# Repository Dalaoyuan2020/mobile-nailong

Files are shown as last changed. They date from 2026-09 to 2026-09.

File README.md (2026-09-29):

# 移动奶龙 / Mobile Nailong

产品目标是**爆改普通行李箱，实现平稳移动、手机遥控与自动跟随主人**；奶龙是可拆装的趣味外观。先完成低速遥控和跟随，再验证裸箱装物、手推与日常随行能力。当前交付处于方案/粗模阶段，尚无可运行实车。

**交给另一Agent审查：先读 [PRD 产品需求](docs/PRD.md) → [PDR 初步设计评审](docs/PDR.md) → [审查任务与证据入口](docs/REVIEW_HANDOFF.md)。** 本方案在 `codex/case26-shell-first` 分支与[草稿PR #1](https://github.com/Dalaoyuan2020/mobile-nailong/pull/1)，未合入前不要用旧main代表当前方案。

当前方案：**正常竖立的行李箱藏在奶龙立牌背后，双管拉杆贴板背，轮子在箱底。** 按参考照片近似描出圆头、鼓肚、抱腹双手和两只脚；立牌是一张 8 mm 平板，彩色图案为印刷示意。

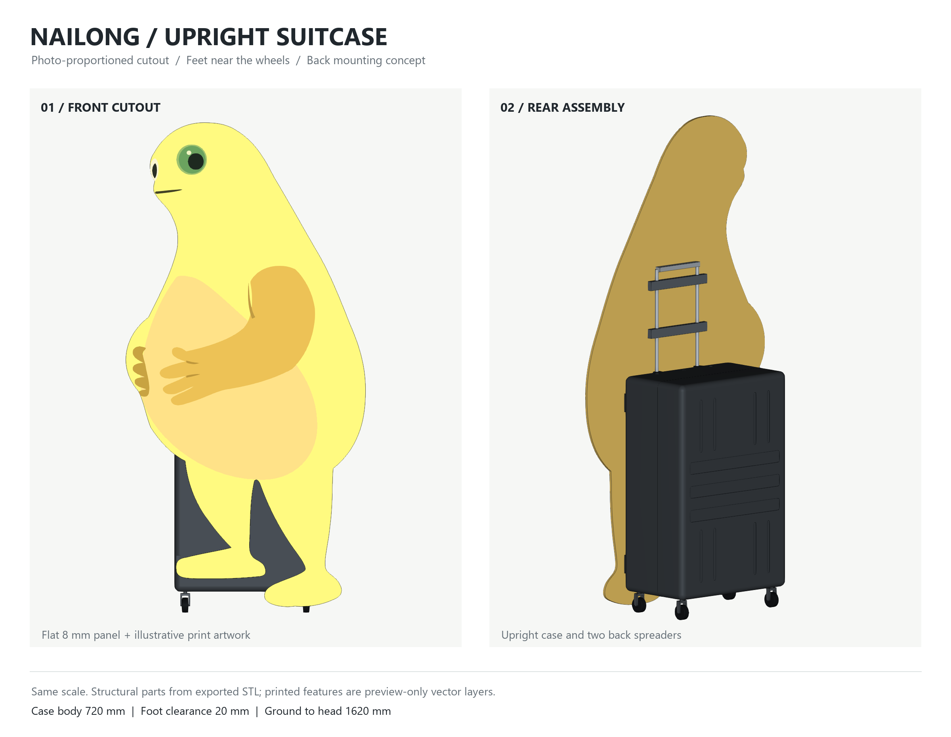
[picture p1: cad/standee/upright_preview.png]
奶龙立牌与背后竖箱


## 当前交付

- [可整块复制的 prompt](docs/PROMPT_STAND_HANDLE.md)
- [装配 STEP](cad/standee/standee_assembly.step) / [STL](cad/standee/standee_assembly.stl) / [侧视](cad/standee/upright_side.png)
- [奶龙轮廓源码](cad/standee/nailong_profile.py) / [正面图案 SVG](cad/standee/front_artwork.svg) / [总装源码](cad/standee/standee.py)
- [材料与候选器件清单](docs/BOM.md) / [功能实现路线](docs/FUNCTIONS.md) / [可复现仿真](simulation/README.md)
- [交互仿真独立页](simulation/nailong-motion.html)：下载/克隆后用浏览器打开；GitHub文件页只展示源码。

默认板高 **1600 mm**，按照片比例宽约 **792 mm**，最低脚尖离地 **20 mm**，头顶离地 **1620 mm**；可用 `--height 1800` 改为 1800 mm 板、约 891 mm 宽、总高 1820 mm。轮廓和图案是参考照片的手工近似，尚非最终印刷稿。

箱壳沿用原 720×470×290 mm 两半壳，只旋转成高720、宽470、深290 mm的竖箱，箱底Z70、箱顶Z790。原 [case26 文件](cad/case26/) 保持原设计坐标，仅总装副本切嵌入式拉杆导座槽。拉杆双管Ø12、管距180，伸出箱顶350 mm。板背X145贴箱面与双管；背面两条概念压条中心Z920/1080，夹具、紧固件和承载能力留待实物验证，正面不画绑带。

当前 CAD 四个轮子是被动外形占位：Ø50、中心X±105/Y±200，左右距400、前后距210 mm。仿真的双电机差速驱动和候选80 mm轮尚未装进CAD；换轮须复核离地间隙、轮舱和接地点。旧540 mm轴距属于横放方案，不用于当前竖箱。

## 复现

```powershell
python -m pip install -r cad/standee/requirements.txt
python cad/handle/handle.py
python cad/standee/nailong_profile.py
python cad/standee/standee.py
python cad/standee/render_preview.py
```

导出过程检查有效实体、STEP回读、STL水密、零件干涉和贴合；印刷面不计入实体STEP。物理仿真使用假设质量与接地点，不能替代称重、实际制动和载荷试验。

## 历史方案

[箱壳初版 prompt](docs/PROMPT_CASE_FIRST.md)、[旧尺寸](docs/DIMENSIONS.md)、[旧计划](docs/PLAN.md)、[旧分层](docs/LAYERS.md)、[旧重心](docs/PHYSICS.md)、[旧电控](docs/ELECTRONICS.md)保留阶段记录。当前需求以[PRD](docs/PRD.md)、执行进度以[任务表](docs/TASKS.md)、外形以[竖箱奶龙 prompt](docs/PROMPT_STAND_HANDLE.md)为准；[资料摘录](docs/SOURCES.md)不作为本机性能证明。

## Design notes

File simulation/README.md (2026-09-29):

# 竖箱移动方案：第一轮筛查

浏览交互结果：下载/克隆后打开 [nailong-motion.html](nailong-motion.html)；GitHub文件页不执行HTML。它是修复后内联可视化的独立导出版，可调高度、配重、速度、转弯与风。[fragment源文件](nailong-motion.fragment.html)保留编辑入口；页面不连接硬件，不实现自动跟随。导出页使用随附样式和状态桥接，通用UI资源可能从允许的CDN加载。

已检查阻断网络时核心图形与控件仍可使用。数值的可复现来源为下面的Python模型；修改fragment后须重新导出完整页，不能只更新其中一份。当前完整页由visualize技能的`python scripts/render.py <fragment> <完整页>`导出，阅读和运行完整页不要求安装该技能。

需求与当前差距见[PRD](../docs/PRD.md)、[PDR](../docs/PDR.md)。本轮只计算当前竖箱奶龙构型；PRD的裸箱0.8 m/s、载物与跟随指标尚未在这里完成独立构型验证，不能只拖动速度滑杆就视为验收。

从仓库根目录运行：`python simulation/simulate.py`。脚本仅用 Python 标准库，参数在 `parameters.json`，会重写 `results.json` 并运行边界校验。一次比较可用 `python simulation/simulate.py --height 1.8 --bottom 0.02 --output simulation/results-1800.json`；默认输出也包含 1.6 / 1.7 / 1.8 m 的对比。

当前 CAD 是被动 Ø50 箱轮；此处计算的是**待实现的后两驱动轮 + 前两万向轮**。接地点 X=±105、Y=±200 mm，后驱动轴 X=-105 mm；轨迹的参考点是该轴中点。支持接地点随脚轮旋转变化尚未建模。Ø80 是备选轮径，采用时必须同时改 CAD 轮舱和离地高度。

默认 0.3 m/s、加减速度 0.25 m/s²、转弯半径不小于 1.5 m，前进左/右转，不原地转、不自动倒车。输出包含直行停车、最小半径转弯停车、断连停车三种轨迹。通信失联 0.2 s 后由仍正常供电的控制器减速停车；默认计算距离 0.24 m，不含检测误差、打滑和控制器失效，断电停车另测。

质量、重心、滚阻、减速度、风阻系数均为**假设**。板轮廓几何可来自照片，但均匀板重与均匀风压仍是假设。6 kg 配重是比较起点，不是实测需求；配重需低位固定，不能自由滑动。固定件 0.5 kg 是暂估。轮距 400 mm/前后距 210 mm 只对应当前竖箱，不沿用历史横箱的 540 mm。

修改 `standee_height_m` 会按相同比例缩放照片轮廓的高和宽、Y/Z 形心与面积；`standee_bottom_m` 单独平移板底和形心高度。默认按 1.6 m 板 1.5 kg 的固定面密度计算，1.8 m 板推算为 1.898 kg；可用 `standee_mass_override_kg` 替换为实测质量。风压作用点采用当前面积形心。`standee_reference` 保留与 CAD 同源的 1.6 m 轮廓基准，输出 `standee_resolved` 给出本次实际值，包含板底/顶部高度。

重心由质量加权计算；接触合力在前后/左右支持边界内只表示通过本准静态筛查。刹车或加速、迎面风、逆向坡度采用最不利同向力矩；转弯用 v²/R。风覆盖整张板，不减掉箱体遮挡。迎风面积/作用点变化、阵风、夹具/KT 弯曲、台阶冲击、脚轮拖曳和动态翻倒都未验证。风阈值是翻倒边界，绝非运行许可风速。

扭矩列出轮端接触需求和减速器输出选型值，后者计入效率 0.7 与系数 2；对两驱动轮平均分力。电机应按实际工作转速下的**持续扭矩**、热限制和驱动电流选，不能用堵转扭矩。另需做后轮附着/制动驻坡试验。

依据：[WPILib 差速运动学](https://docs.wpilib.org/en/stable/docs/software/kinematics-and-odometry/differential-drive-kinematics.html)、[NASA 风阻公式](https://www1.grc.nasa.gov/beginners-guide-to-aeronautics/drag-equation/)。阻力系数 1.2 是本项目假设，未对奶龙切型板标定。

下一步：量整机/各部件重量及轮廓、称重或悬挂测重心；低速架空验证左右轮和失联停止；再在有人监护的空地测试直行、缓转、停车。结构/多体动态仿真与实车测试应在驱动、夹具和质量确认后进行。

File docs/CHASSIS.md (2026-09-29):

# L1 底盘：买还是自制

> 历史横放底盘选型：当前为竖立箱体与普通箱轮，本轮没有驱动底盘；下文采购与承载结论需按新方案复核，几何见 [当前 prompt](PROMPT_STAND_HANDLE.md)。

偏好：**能自制就自制**。工期紧再买现成。

判据只看一个数：距展示 / 路演还剩几天。

| 剩余 | 走哪条 |
|---|---|
| ≥ 10 天 | 自制 |
| 5–9 天 | 自制架 + 买电机遥控，不自绘 PCB |
| < 5 天 | 买 20 kg 成品底盘，箱子直接扎上去 |

---

## 价档分档（2026-09-29 淘宝见到的价）

| 档 | 大概 | 什么 | 能不能驭 17–22 kg |
|---|---|---|---|
| 电赛板 | 20–80 | 亚克力 / 薄铝 + TT 电机 | 不行 |
| **自拼重载** | **150–250** | 铝板 + 520/775 减速电机 + 驱动 + 2.4G 遥控 | 能，要自己对轮距限速 |
| 成品 20 kg 平台 | 300–450 | 500×300 铝合金四驱，常见一张 **395** | 能，开箱驭箱 |
| 履带 / 车间平车 | 800–几千 | 果园车、工厂平车 | 过大，不买 |

搜索词：

- 自制：`520 减速电机` `775 减速电机` `BTS7960` `2.4G 遥控车` `94dd板 400x600x5`
- 现成：`94dd合金重载底盘 20kg 四驱 遥控`

---

## 路径 A · 自制（偏好）

零件约 150–250：

| 件 | 约 |
|---|---|
| 铝板 400×600×5 或 500×300×5 | 30–60 |
| 520 或 775 减速电机 × 2（后驱） | 50–80 |
| 高流驱动 BTS7960 或双路大电流 | 20–40 |
| 万向轮 4 寸 × 2（前） | 15–25 |
| 驱动轮 + 联轴 | 20–40 |
| 2.4G 遥控接收 | 25–40 |
| 12V 5Ah 三元或铁硼 | 30–50 |
| 螺丝拐角 | 10 |

形状：后两轮差速驱动，前两轮万向从动。不要麦轮。
轮距 ≥ 360 mm，轴距 ≥ 480 mm。
PWM 必须 2 秒斜率，禁止两轮反转原地转。

工时大概 3–5 晚：下单 1 天 + 对孔装配 1 晚 + 调速 1 晚 + 扎箱跑 1 晚。

## 路径 B · 现成（时间不够）

一张标 20 kg 的铝合金四驱平台，常见 **395**，台面约 500×300。
箱子闭死扎在台面上。遥控太敏就把摇杆行程限一半。

## V1 共同部分（两条路都要）

- 26 寸硬壳 80–150
- 1.6 m KT 立牌 40–80
- 配重 8 kg
- 扎带 20
- 拆原装万向轮
- V1 **不开箱**

V1 合计：自制约 **350–550**；现成约 **420–750**。

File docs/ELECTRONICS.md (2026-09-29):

# 电控

> 历史草案：下文的 BLE RSSI 跟随和倾斜后退不用于当前方案。当前实现路线见 [FUNCTIONS.md](FUNCTIONS.md)，选型见 [BOM.md](BOM.md)；倾斜或失联应停机，不自动后退。

建模不依赖这一页。装配时用。

- ESP32
- 双路驱动 + 两只减速电机（后轮）
- MPU6050 贴在立牌背面中高，不是贴在箱上
- 超声 × 3：箱前缘中、左前、右前
- DFPlayer + 喇叭
- 电机电源串急停
- 手机 BLE 摇杆；跟随 = 跟主人手机 RSSI

PWM 斜率：摇杆打满也要 2 秒才到 0.30 m/s。禁止原地甩尾。
俠仰/横滚 > 8° 持续 200 ms → 停转并后退。

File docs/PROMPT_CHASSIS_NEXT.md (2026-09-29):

# PROMPT · 箱子已有，这一轮只做底盘

> 历史横放底盘 prompt，已停用。当前竖立箱体仅有普通箱轮，没有驱动底盘；姿态和轮位见 [当前 prompt](PROMPT_STAND_HANDLE.md)。

从下面 `---` 复制到文末，贴给本地 Claude / Codex。

---

注意：以下横放底盘方案仅留档，不能直接套到当前竖立箱体；本轮不按此旧 prompt 新建驱动底盘。

你在仓库 `mobile-nailong` 里推进 L1。

箱子已经在本地画好了。**不要重画箱子，不要改箱子外形。**
这一轮只设计铝底盘板 + 四轮装配。
不要建立牌、不要建绑带、不要建 ESP32 盒、不要建配重块。

路径：自制底盘（路径 A）。参考 `docs/CHASSIS.md` 和 `docs/LAYERS.md`。

## 约束

- 箱子躺平。底盘在箱底下面。
- 坐标跟箱子一致：原点在箱底外表面中心，+X 前进，+Z 向上。
- 箱底四个 M6 轮装孔已经按轮距 400 mm、轴距 540 mm 布好。底盘的四个孔必须对上这四个孔。
- 底盘板厚 5 mm，材料 6061。
- 底盘平面尺寸约 500 × 360 mm，不得比箱脚印（720 × 470）更宽超过 20 mm。
- 后两轮驱动（差速），前两轮万向从动。轮径 50 mm。
- 不要麦克纳姆轮。不要履带。
- 电机用简模：直径 37 mm 的圆柱，长 70 mm，贴在底盘下表面靠后轴。
- 电机和轮不得碰箱壳。离地间隙 ≥ 15 mm。
- V1 箱子不开盖。底盘不要挡箱盖分型线，但不用为开盖让位。

## 要交付

放到 `cad/chassis/`：

1. `chassis.scad` 或 `chassis.py`（CadQuery / OpenSCAD，和箱子同一套工具）
2. 和已有箱子装在一起的装配（箱在上，底盘在下）
3. `NOTES.md`：十行以内，写板尺寸、四孔坐标、轮距轴距、离地间隙

先画底盘板和四孔，再画轮和电机。不要改箱。画完等我看装配侧视。

---

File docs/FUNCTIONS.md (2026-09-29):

# 功能实现路线 · 先形状，再能稳稳地走

完整产品范围见[PRD](PRD.md)，可行性缺口见[PDR](PDR.md)。**手机遥控与自动跟随均为核心需求**：M1先验证稳定遥控，M2必须交付低速跟随，M3再验证裸箱日常使用；完成M1不能宣称整个产品完成。

当前交付是正常竖箱、贴箱奶龙切型板与背部固定占位的粗模；没有驱动底盘或已运行固件。板高默认 1600 mm，可调至 1800 mm，脚底 Z=20 mm，因此龙头离地约 1.62–1.82 m。它不从箱顶再叠高。固定方法未锁定，先验证背撑、两点分压夹持和下部承托。

## M1 · 稳定遥控工程样机

| 功能 | 实现方法 | 首版验收目标 |
|---|---|---|
| 手机遥控前进/停止 | 手机 BLE 控制界面 → ESP32 → 两路 H 桥 → 后两带编码器减速电机 | 放开摇杆停；最高 0.30 m/s；加速度不超过 0.25 m/s²；首版不开放倒车 |
| 缓慢转弯 | 后两固定驱动轮差速，前两万向；编码器闭环修正左右轮速 | 转弯半径不小于 1.5 m；禁原地自旋和左右轮反向甩尾 |
| 通信丢失停机 | 指令含序号/心跳；超时后目标速度归零，由健康且正常供电的控制器受控减速 | 台架初值 200 ms，实测通信延迟与停车距离后调整；恢复通信不自行起步 |
| 近障停车 | 三个前向传感器 + 低位触碰条进入统一停车状态 | 障碍消失后仍需人工重新使能；不自动后退 |
| 倾斜停车 | 箱体 IMU，融合倾角和角速度；阈值由重心/倾覆仿真与实物测试定 | 避开加速噪声误判；倾斜时停机锁定，不用“后退”补救 |
| 实体急停 | 常闭急停回路切断驱动电源；控制器独立低压供电记录状态 | 急停复位不自动启动；断电后的滑行距离单独实测 |

限速、阈值和停车逻辑是待实现的设计目标。0.30 m/s、减速度 0.25 m/s²、200 ms 延迟的理想停车距离为 `v×延迟 + v²/(2a) ≈ 0.24 m`，尚未包含传感器滤波、打滑、脚轮摆动和障碍余量；检测触发距离须大于实测停车距离再留余量。此数值依赖健康控制器受控减速，不能把断电等同于立即刹停，坡道保持需另外验证或增加机械驻车制动。[仿真假设与复现](../simulation/README.md) · [本轮计算结果](../simulation/results.json)

```mermaid
flowchart LR
  Phone[手机 BLE 摇杆与心跳] --> Controller[ESP32 状态机与速度闭环]
  Sensors[编码器 / 箱体 IMU / 距离与触碰] --> Controller
  Controller --> Driver[左右 H 桥]
  Driver --> Wheels[左右后驱动轮]
  Battery[成品电池与保险丝] --> Stop[实体急停开断回路]
  Stop --> Driver
  Battery --> Logic[逻辑电源]
  Logic --> Controller
```

控制状态按“待机 → 人工使能 → 遥控 → 停车/故障”实现。速度闭环可从 100 Hz 台架起调，手机指令可从 20 Hz 起调；超时、过流、传感器异常与急停优先级高于摇杆。车体宽向轮距按 0.4 m 分配左右轮速；驱动设计以当前 210 mm 轴距为起点，不能把旧横箱 540 mm 轴距搬过来。ESP32 的 BLE、脉冲计数和电机 PWM 能支持这条实现路线。[Espressif 数据手册](https://documentation.espressif.com/esp32_datasheet_en.html)

奶龙脚部已接近地面，板又比箱体宽：前向测距头要通过板轮廓空隙、左右侧支架或单独透出口看到前方，不能沿用被 KT 板堵住的旧箱壳孔位。以 1600 mm 模型约 790 mm 最大板宽核对门框、转弯扫掠和行人间距；1800 mm 变体等比更宽。箱体 IMU 只反映箱体姿态，立牌晃动与夹持松动要另外做结构试验。

## 驱动底部怎么选

| 路径 | 好处 | 必须解决的事 | 当前建议 |
|---|---|---|---|
| 保持竖箱外形，后轮改差速驱动 | 接近用户参考照片，体积小 | 窄底座稳定性、轮座加强、电机容纳、板脚离地、坡道制动 | 先做可拆台架，用假负载验证后再回填 CAD |
| 成品遥控底盘承载竖箱 | 可减少传动制作 | 核对真实载荷、制动、限速接口；底盘会增宽/增高，必须重新排板脚与轮位 | 若前一路制造或成本不合适再比较，不先买 |

电机与电源的候选及约束见 [材料清单](BOM.md)。首轮仅在平整室内、有人看护的低速试验场景验证；越门槛、坡道、室外风载与人群穿行尚未具备依据。

## M2 · 自动跟随与奶龙登场（必交付）

跟随需要目标ID、距离、相对方向、时间戳和有效标志；先比较支持测角的UWB随身标签方案与相机/AprilTag方案，路线见[PDR定位评审](PDR.md)。手机负责启动、模式与停止，定位模块不直接驱动电机。允许随身标签是待评审假设，不能把普通手机BLE连接自动等同于精准定位。

先绑定目标并人工启动；跟随控制提出速度/转弯请求，与遥控共用限速、编码器闭环和全部停止条件。建议初始跟距1.8 m，定量验收按PRD A04–A05执行。目标信息超过200 ms未更新、身份不符或质量无效则进入停车；目标重新出现后不自动补跑。目标到车后或转弯无法满足半径限制时先停，不能原地甩尾。

奶龙登场先做按住触发的一次短动作，建议≤1 m且≤5 s，先到者结束；松手、接管、失联或障碍均能中止。跟随和登场不是同时输出速度的两个控制器，不做无人值守循环表演。

BLE RSSI只能反映受环境影响的信号强弱，单个RSSI不提供可靠方位。Bluetooth方向定位采用AoA/AoD与天线阵列，不能直接用普通RSSI代替。[Bluetooth Direction Finding](https://www.bluetooth.com/learn-about-bluetooth/feature-enhancements/direction-finding/)

## M3 · 实用裸箱与增强功能

1. **人工倒车**：补后向探测与倒车视场、制动验证后再开放；故障处理始终不自动后退。
2. **声音互动**：停车或手动按钮触发音效；ESP32 通过 UART 控制 DFPlayer，设置冷却时间避免连续播放。先不让声音检测直接驱动车辆。[DFPlayer 官方资料](https://www.dfrobot.com/product-1121.html)
3. **实用裸箱**：开盖、载物、断电手推、续航与日常跟随分别验收；PRD提出的0.8 m/s目标必须重新评审传动与制动。当前0.3 m/s奶龙模式不直接放宽限速，也不替代日常随行验收。

## 验证顺序

1. **外形与静态结构**：确认奶龙切型、1.6/1.8 m 两档、板贴箱、脚轮不蹭；称各件质量，定位重心，确认下部承托和上部夹持能分担载荷。
2. **参数仿真**：比较高度、配重、轮径和板前偏；核对倾覆余量、平地/坡面扭矩、速度与理想停车距离。仿真结果不替代 KT 挠曲、真实脚轮接触或风洞/路测。
3. **台架与空车**：先架空验证旋向、编码器、限流、急停、断连与复位，再用等质量假负载低速跑直线和大半径转弯，记录电流、温升和制动距离。
4. **定位与跟随**：固定场地采集目标误差/延迟/遮挡日志；用假负载完成跟随、失效停车和遥控接管，再装板复验。
5. **装板与实用裸箱**：装板从0.10 m/s逐级提高，检查晃动、松动、板材压痕、脚尖和探头遮挡；再做受控登场。裸箱速度、装物、开盖、手推与续航另按PRD验收，音效可后续添加。

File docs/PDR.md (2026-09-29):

# PDR · 智能改装行李箱初步设计评审

版本0.1 · 2026-09-30 · **待评审，未通过制造/采购放行。** 对应需求：[PRD v0.1](PRD.md)。这里的PDR是Preliminary Design Review，负责判断方案、证据和缺口。

## 1. 当前结论与证据

| 项目 | 已有证据 | 尚不能推导的结论 |
|---|---|---|
| 外形 | 竖箱、奶龙切型板、拉杆、背面压条的STEP/STL与预览；默认16个有效实体，几何检查无实体穿插 | 不代表夹具抗拔、壳体强度、拉杆寿命或真实可制造性合格 |
| 稳定与运动 | [脚本与说明](../simulation/README.md)，24项计算断言，1.6/1.7/1.8 m对照 | 不包含真实轮胎附着、脚轮摆动、板弯曲、阵风及结构动态响应 |
| 交互估算 | [可浏览的仿真页](../simulation/nailong-motion.html)，可调板高/配重/速度/转弯/风 | 页面不连接实车；左侧为示意轨迹，不是自动跟随算法 |
| 控制与定位 | [功能路线](FUNCTIONS.md)及候选[BOM](BOM.md) | 目前没有电机装配、手机应用、控制固件或自动跟随实现 |

因此，本轮可以进入方案审查和实物测量；现有证据不能作为整车采购定型或M1–M3完成证明。

## 2. 机械路线

继续使用正常竖立行李箱，后两固定驱动轮+前两从动万向轮是待验证路线。箱身高720×宽470×深290 mm；当前轮中心X±105/Y±200 mm，左右距400、前后距210。原壳体保留历史540 mm孔距，不能把该孔距当作当前支持范围。

奶龙为8 mm切型平板，默认1600高/792宽、脚底Z20；拉杆露出350，双管距180，背面两条压条中心Z920/1080。压条仍是概念模型：还需要下部承托、KT分压/背撑、管夹锁止、箱内背板与载荷路径。板重量不能只靠薄壳或小胶点承受。

实用形态要求箱盖能打开、载物区可用、断电可手推。低位配重、驱动和电池会争用空间并增加搬运负担；当前6 kg只是仿真起点，应先称重与优化布局，再决定是否需要。装/拆奶龙后必须分别识别质量与速度配置。

## 3. 电控与停止链

```mermaid
flowchart LR
  Phone[手机 遥控/模式/停止] --> Supervisor[ESP32 控制权与状态机]
  Locator[目标定位 距离/方向/ID/时间戳/有效性] --> Follow[跟随控制 候选速度]
  Follow --> Supervisor
  Sense[编码器 IMU 近障 触边] --> Supervisor
  Supervisor --> Limit[限速 加速度/转弯限制 故障停车]
  Limit --> Drive[两路驱动与轮速闭环]
  Power[成品电池 保险丝 急停开断] --> Drive
  Drive --> Wheels[左右驱动轮]
```

目标定位只提交带时间戳和有效标志的相对位置，不直接控制电机。手机遥控、跟随和登场只能有一个运动请求来源；停止、过流、倾斜、近障、失联和目标失效均可撤销使能。断电停止与健康控制器受控制动是不同工况，均须实测；恢复连接/目标或急停复位后仍保持待机。

驱动轮编码器闭环与故障处置留在车端，手机/定位进程崩溃不能留下最后一个非零速度。首轮200 ms有效期要求定位刷新与端到端延迟留出余量；信号质量下降时停车，不能用平滑滤波把旧数据伪装成新测量。

## 4. 自动跟随：必须验证距离和方向

| 路线 | 拟用方式 | 优点 | 需证实的条件 |
|---|---|---|---|
| UWB测距+测角，主人带标签 | 车端支持AoA/PDoA的接收配置，目标标签与手机分别负责定位和操作 | 目标身份明确，可先不做人物识别 | 天线/模块是否真的支持方位、遮挡/多径、前后歧义、更新率、成本与安装位置 |
| 摄像头+AprilTag随身标记 | 标定相机、已知尺寸标记，识别指定ID并估计相对位置；单独计算单元给ESP32发结果 | 标记与日志容易观察，适合跟随算法台架 | 标记朝向/遮挡/光照、有效视场、相机延迟；增加算力、电源、质量与布线 |
| 直接跟人物外观或手机定位 | 后续评估 | 使用时可少一个标签 | 身份切换、遮挡恢复、手机兼容性与本地处理成本；本轮不据此承诺可用 |

优先拿能够输出**目标ID、距离、方位、有效性和时间戳**的完整评估方案做台架，测完再选UWB或视觉。允许随身标签是当前评审假设；若产品要求只有手机，必须列出支持的具体设备与接口。单个BLE RSSI、单个仅测距UWB或超声“看到前面有人”不能直接满足目标跟随需求。

官方依据：[Qorvo QM33120WDK1](https://www.qorvo.com/products/ek/QM33120WDK1)明确区分AoA/非AoA子板与单双天线，可用于测距/测角评估；这不代表任意UWB板都有方位输出。[AprilTag官方](https://github.com/AprilRobotics/apriltag#pose-estimation)支持位姿估计，需要标记尺寸与相机内参。以上只是候选路线依据，尚未在本项目验证。

跟随算法建议先做：绑定目标 → 校验有效期 → 限定跟距误差/方位误差 → 生成前向速度与转弯请求 → 共用运动限幅与障碍停车。原地掉头或目标移到车后时先停并要求重定位，不强行甩尾追上。无绕障路径规划时，障碍挡路就停并提示用户。

## 5. 关键可行性缺口

| ID | 缺口 / 与PRD的关系 | 审查需要的证据 |
|---|---|---|
| D01 | 210 mm前后支持距、1.6–1.8 m大板与风载 / R01、R05 | 实物轮接地点/脚轮旋转包络、称重重心、静态/动态倾覆余量 |
| D02 | 低位20 mm脚尖和宽板会擦地/挡探头 / A06 | 带载挠曲、转弯扫掠、实际通道宽度与传感器全宽视场 |
| D03 | 拉杆、KT、夹具及薄壳载荷路径 / R05 | 下部承托、分压背板与锁止详图，载荷与振动试验；当前压条不可直接当制造图 |
| D04 | 日常跟随速度与当前传动不同 / A10 | 电机在所需转速的持续扭矩、温升、制动与附着试验，不能用堵转值选型 |
| D05 | 跟随定位路线未选 / R03、A04–A05 | 原始目标轨迹、误差/延迟分布、遮挡与混入目标测试、手机/标签兼容性 |
| D06 | 仍要当行李箱使用 / R07、A08 | 开箱/储物/提拉/断电手推实测；电池、配重和内骨架的布局 |
| D07 | 电池、电流、续航、总预算未定 / A09 | 带载电流与功率记录、成品电源选型、厂家报价；不直接沿用旧横箱预算 |

特别核对：PRD裸箱0.8 m/s是新提议，不是把现有限速滑杆调大即可。Ø50轮需要约306 rpm；当前BOM中200 rpm空载候选电机连该空载轮速也达不到。在当前0.25 m/s²减速度、0.2 s延迟假设下，0.8 m/s停距为1.44 m，已经接近1.5 m跟距下沿。必须重选传动、制动/跟距与速度配置，或调整产品指标；不能拿奶龙低速算例验收裸箱日常跟随。

已有1.6 m算例使用总重15.5 kg、低位配重6 kg，重心约302 mm，0.3 m/s断连受控停距0.24 m。1.8 m板按同面密度扩大后总重约15.898 kg，重心约327 mm。在5 m/s不利向风叠加加减速的假设筛查中，前后余量由约+15 mm变为−20 mm；这是模型对高度的敏感性证据，不是允许运行风速。

## 6. 评审后推进顺序

1. 实测现有箱、轮位、质量与开箱空间；确定固定与下部承托，更新真实几何参数。
2. 审定M1电机/轮座/加强件/电源候选；架空验证转向、编码器、限流、停止与复位，再做假负载遥控。
3. 在同一路线对跟随定位候选采集数据，明确是否接受标签，冻结M2的传感器与预算。
4. 接跟随控制与公共停止链；先假负载，再装奶龙；完成PRD的低速跟随与登场验收。
5. 单独评审裸箱0.8 m/s、载物、续航和手推；必要时修订传动及速度目标，再完成M3。

评审结论使用“通过 / 有条件通过 / 需修改”，逐项列证据、影响的需求ID、整改动作与复验方式。几何通过不代表结构通过，低速遥控通过也不代表自动跟随或日常行李箱功能通过。

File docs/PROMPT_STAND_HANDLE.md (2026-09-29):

# PROMPT · 竖立行李箱背负奶龙立牌

从下面分隔线复制到文末，整块贴给本地模型。

---

你在仓库 mobile-nailong 修改现有模型。用户已用照片纠正设计：正常竖立的行李箱，轮子在底下，拉杆向上；奶龙立牌贴在箱子的大面，箱子藏在板后。以本段最新要求覆盖旧“横放箱子、矩形板叠箱顶、三绑带”的要求。

先把大概形状建对，再列材料清单、做运动与稳定性仿真，并说明功能怎么实现；固定方式尚未定型，不围绕绑带细节浪费时间。

1. 坐标 +X 正脸/+Y 左右/+Z 向上，地面Z0。沿用 cad/case26/ 原壳体，通过 cad/handle/case_pose.py 旋转平移；竖箱范围 X±145、Y±235、Z70…790 mm，高720×宽470×深290。仅总装副本开拉杆导座槽。
2. 当前四个普通箱轮Ø50，中心X±105、Y±200，轮底落地，左右距400、前后距210。旧540是横放方案孔距，不套到竖箱。CAD中的轮子只是被动占位，没有驱动底盘。
3. 双管拉杆Ø12、管距180；管轴X139/Y±90，最高Z1140，即伸出箱顶350。导座嵌入箱壳，管前切面X145贴板背。此档用于审形，不拉长到奶龙头顶。
4. 奶龙必须有参考照片的形状：圆头短嘴、大眼、内收脖颈、圆肚子、抱腹手臂、分开的两只脚；不要换回黄色矩形。用 cad/standee/nailong_profile.py 的可修改轮廓及印刷图层。
5. 立牌是一张8 mm厚的KT轮廓板，不是立体雕塑；正脸朝+X，板背X145贴箱面和拉杆。本体高1600…1800，默认1600；按照片比例缩放，默认宽约792，不强压到旧500宽。
6. 最低脚尖离地20 mm，默认总高1620；1800板总高1820。板下段贴箱外侧，不插入箱腔，不叠箱顶，不做人字双板。脚附近间隙需后续按地面条件实测。
7. 暂用两条背面横压条表示固定位置（中心Z920/1080，250×16×30 mm，双管槽），正面不画三条黑带。它们是安装概念，未设计最终夹具/螺钉/承载，不可当作制造图。
8. 印刷图案是预览用零厚度平面及SVG，实体STEP只有轮廓板。不要把眼睛、肚子、手臂做成凸起的实体零件。
9. cad/handle/ 和 cad/standee/ 保留CadQuery源码，更新STEP/STL、真实几何正背面与侧视预览；两处NOTES各十行以内，写外形、拉杆伸出、管距、固定概念、最低脚尖和头顶高度。
10. 产品范围读docs/PRD.md，技术缺口读docs/PDR.md；docs/BOM.md列外形、驱动和跟随定位候选，docs/FUNCTIONS.md说明控制路线。先做稳定遥控M1，再做必交付的自动跟随M2；不把RSSI当可靠方向，不把粗模声称为功能实车。语音可后续增强。
11. simulation/ 先做参数可改、可复现的运动学和准静态估算：直行、转弯、受控刹停/失联、质量重心、倾覆边界与电机扭矩。假设和未建模项写清楚，勿把计算当实测；现有CAD被动轮和候选驱动轮尺寸须区分。

检查箱子直立、奶龙轮廓比例、板脚接近轮底、背面贴合、零件无穿模。完成本轮模型、清单和仿真后停下，等用户看外形和功能取舍。

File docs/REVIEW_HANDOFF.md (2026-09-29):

# 给下一位Agent的审查入口

当前审查分支：`codex/case26-shell-first`；[草稿PR #1](https://github.com/Dalaoyuan2020/mobile-nailong/pull/1)。先确认checkout的是PR最新head；主分支未合入前不能代表本方案。

先读[PRD](PRD.md)确定产品目标，再读[PDR](PDR.md)找设计证据和缺口，随后核对[BOM](BOM.md)、[功能路线](FUNCTIONS.md)、[总装侧视](../cad/standee/upright_side.png)及[仿真说明](../simulation/README.md)。

已交付：竖箱奶龙粗模、可回源脚本与STEP/STL、16实体几何验证、可复现的运动学/准静态估算及24项断言、修复后的交互估算页。尚未交付：真实驱动、控制固件、手机应用、目标定位、自动跟随和实物承载测试。

本轮交接检查：24项计算断言通过；独立仿真页联网/阻断网络两种条件下均可初始化、调板高与速度，360 px宽度无横向溢出、无脚本异常；当前Markdown本地链接已核对。CAD未因文档改动重新生成，原几何检查记录见`cad/standee/validation.json`。

## 可直接复制的审查任务

```text
请审查 mobile-nailong 仓库 codex/case26-shell-first 分支最新提交及PR #1，不要基于旧main的横放方案给结论。
先读 docs/PRD.md、docs/PDR.md、docs/BOM.md、docs/FUNCTIONS.md，再核对CAD和simulation。
产品是爆改普通行李箱：平稳、手机遥控、自动跟随主人；奶龙是可拆换装。自动跟随是核心交付，当前尚未实现。
当前外形是正常竖箱藏在1.6–1.8m奶龙切型板后，最低脚尖离地20mm；现有轮子仅被动占位，固定夹具未定型。
请重点审：支持距与重心、风与板挠曲、拉杆/夹具/壳体载荷、开箱/储物/手推、驱动持续扭矩与轮速、制动/断电滑行、跟随距离与方位来源、目标丢失、传感器遮挡及控制权。
区分已验证的代码/几何、假设计算、待实现功能和待实测性能。PRD中0.8m/s裸箱跟随等建议指标需审，不得当成既成能力。
运行 python simulation/simulate.py --output <临时结果路径>；浏览器打开 simulation/nailong-motion.html，可调整高度/配重/速度/半径/风。
不要自动重导出全部CAD、改模型、采购、合并PR或运行硬件。先交审查意见。
输出：通过/有条件通过/需修改；按严重程度列具体文件位置、问题、证据或复现、对应需求ID、最小整改和复验方法。找不到依据就标未验证，不凭外形图放行制造。
```

可运行的检查：

```powershell
python simulation/simulate.py --output review-results.json
```

CAD环境与复现见[README](../README.md)。`cad/case26/`保留原壳体设计坐标，当前总装由`cad/handle/case_pose.py`旋转摆正；不要把旧540 mm孔距当作竖箱前后支持距。

旧PLAN/TASKS等横放设计保留历史链接，不作为当前需求。`SOURCES.md`是资料摘录，未在本仓库复现实验，不能把别人的性能值当成当前样机性能。

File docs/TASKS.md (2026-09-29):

# 当前任务 · 智能改装行李箱

产品目标与验收见[PRD](PRD.md)，设计缺口见[PDR](PDR.md)。本表取代旧横放任务；自动跟随是必交付功能。

## M0 方案与交接

- [x] 竖箱与1.6–1.8 m奶龙切型粗模、拉杆与固定占位
- [x] STEP/STL、正背面与侧视、几何验证
- [x] 初步运动/稳定性计算、24项断言与交互估算
- [x] PRD、PDR、BOM、功能路线和[审查入口](REVIEW_HANDOFF.md)
- [ ] 另一Agent独立审查并关闭关键问题
- [ ] 实测箱型号、重量、轮接地点、储物/开箱空间；冻结实际参数

## M1 稳定遥控工程样机

- [ ] 完成轮座、加强件、下部承托与夹具详图/验证
- [ ] 选电机、驱动、电源并做架空旋向/编码器/限流验证
- [ ] 手机界面、车端轮速闭环与唯一控制权
- [ ] 受控停车、断连、近障、倾斜、实体急停和复位行为
- [ ] 假负载低速起停、缓转、电流/温升与停车距离记录

## M2 低速跟随与奶龙闭环

- [ ] 冻结随身标签是否可接受、定位路线与成本
- [ ] 实测目标ID、距离、方向、刷新率、延迟、遮挡与误跟
- [ ] 跟随控制共用运动限幅/停止链；目标丢失和遥控接管验收
- [ ] 装板复验、可拆换装和受控短距登场

## M3 实用智能行李箱

- [ ] 评审裸箱0.8 m/s建议目标，重选必要的传动与制动参数
- [ ] 冻结并验证载物、储物空间、开合、提拉、断电手推与续航
- [ ] 分别验收奶龙/裸箱模式；发布实测日志与能力边界
- [ ] 可选手动音效、后向探测及人工倒车

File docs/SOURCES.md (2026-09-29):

# 资料（只放链接和原文里写明的事）

收集日：2026-09-29。不写方案。

## 1. 行李箱跟随 / 电动箱

- [US10180683B1](https://patents.google.com/patent/US10180683B1/en) Robotic platform follow a user device
  - Follow me / manual 两模式
  - 障碍识别后改路
  - 手机里的加速度计、陀螺、指南用来算用户相对箱子的角度
  - 电机和轮之间加悬架；平台和箱壳之间加悬架
- [CN110250695B](https://patents.google.com/patent/CN110250695B/zh) 智能跟随行李箱
  - 动力轮沿箱底 **长边** 方向走，比沿短边走更难前后翻
  - 原因：前后从动轮距离加大，力臂加长
  - 文中写起步、急停、凹凸路容易因重心高而倒
- [CN110664075A](https://patents.google.com/patent/CN110664075A/zh) 自动跟随行李箱
  - 超声 + GPS + MEMS 六轴陀螺 + 摄像头
  - 电池在箱底
- [WO2026016603A1](https://patents.google.com/patent/WO2026016603A1/zh) 电动驱动装置及电动行李箱
  - 外挂盒子：轮和方向杆可伸缩，可拆下收进箱里
- CSDN：[基于STM32的智能行李箱](https://blog.csdn.net/weixin_29185167/article/details/164307162)
  - HC-SR04 跟人
  - MPU6050 跌倒检测；文中示例阈值 pitch/roll **60°**
  - FSR402 称重
- IJEDR PDF：[Autonomous luggage trolley](https://rjwave.org/ijedr/papers/IJEDRB003042.pdf)
  - 铝架 60 × 40 × 80 cm，中间放登机箱
  - 前万向从动 + 后驱动
  - 电路放货舱下层，文中写明是为了压低重心
  - 跟距 0.5–1.2 m；30 次室内 87%
- IJSRD PDF：[Design, Fabrication, Assembly and Testing of Motorized Suitcase](https://www.ijsrd.com/articles/IJSRDV7I70164.pdf)
  - 24 V 250 W 电机、链传、钢管架 558.8 × 355.6 × 355.6 mm
- TAR UMT：[Design and Fabrication of Motorized Suitcase](https://eprints.tarc.edu.my/id/eprint/10284)
  - 目标空重 <10 kg，实测 15.5 kg；尺寸 0.65 × 0.25 × 0.38 m
- JSME：[Inverted Two-Wheeled Luggage Transport Vehicle](https://www.jstage.jst.go.jp/article/jrobomech/33/3/33_643/_pdf)
  - 两轮倒立行李车，静不稳，要闭环
- Royal Society：[The rolling suitcase instability](https://royalsocietypublishing.org/rspa/article/473/2202/20170076/57351/The-rolling-suitcase-instability-a-coupling)
  - 拖行李箱侧摇与平移耦合；超过某个 Froude 数会翻

## 2. 立牌 / 人字牌 / 风载

- eSigns：[How to Secure A-Frame Signs Outdoors](https://www.esigns.com/signs-101/how-secure-a-frame-signs-in-windy-areas.html)
  - 配重要装在底座里；不要把重物挂在牌上（会抬高重心）
  - 两侧注满且对称
- JS Burgess：[Wind Loading Considerations for Stillages & A-frames](https://www.jsburgess.co.uk/stillages-a-frames-wind-loading-considerations/)
  - 倾覆：重心投影跑出底边
  - 风压按 EN1991-1-4
  - 句子：Keep the CoM low and the base wide
- Access Display [Tip 'n Roll 说明书 PDF](https://cdn.shopify.com/s/files/1/0036/4393/2761/files/tip_n_roll_sidewalk_sign.pdf)
  - 底座注水 **2.5–4 加仑**（约 25–40 lb）
  - 板背加 Stabilizer Plate 贴杆
  - 搬运：提顶倾到轮上推
- Wind Sign 说明书：板每面 ≤ 5 lb；配重表 70 lb → 40 mph，100 lb → 55 mph
- Illinois IDOT PDF：[temporary sign supports wind](https://www.ideals.illinois.edu/items/140293/bitstreams/452161/data.pdf)
  - 20 mph 可部署；40 mph 不推荐任何测试过的临时牌架
  - 刚性支撑要加沙袋
- 人形 KT 架供货：常见展示高 **1.6–1.8 m**；带万向轮款约 300–500
- KT 厚度供货文：5 mm 约 0.8 kg/m²；3–5 mm 不推荐户外

## 3. 底盘现货价格（搜索页，不是推荐）

- 铝合金大载重 500×300，标 20 kg，页面价 **395**
- 同店 500×400 起 **511**
- 电赛 4WD 铝板 **3.7–50**
- 履带运输底盘 **850–4980**
- 平板电动遥控车 **2188**

搜索词：`铝合金重载底盘 20kg` `520 减速电机` `2.4G 遥控车`

## 4. 26 寸箱外形（行业对照，含轮含把手有差）

- [Indexia 2026 对照](https://indexiahq.com/suitcase-size-guide-2026/) 26 寸约 **68–73 × 43–48 × 27–31 cm**
- LuggageX 26"：66 × 47 × 31 cm

## 5. 与拉杆固定有关

- Tip 'n Roll：立杆插底座中孔，板背用 Stabilizer Plate 夹在杆上
- 人像立牌铁架供货：主杆预留螺丝孔打 KT / PVC

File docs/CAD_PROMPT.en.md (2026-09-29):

# CAD prompt (English)

> Archived horizontal layout; superseded by the [current upright suitcase prompt](PROMPT_STAND_HANDLE.md). The board now rests against the front broad face of the upright case. Do not use the old orientation or wheelbase below for the current assembly.

You are a mechanical designer. Build an assemblable CAD model for "Mobile Nailong".

A 26-inch hard-shell suitcase lies on its largest face and acts as ballast plus a load cart. A 1500 × 500 × 8 mm KT standee is strapped on TOP of the suitcase (yellow cartoon dragon, front facing +X). Under the case: a flat drive plate, two rear driven wheels, two front casters.

Coordinates: origin at underside center of the case. +X forward, +Z up.
Case footprint 720 × 470 mm, shell 290 mm thick. Chassis plate 8 mm under the case, 50 mm margin. Wheel radius 50 mm. Track 400 mm. Wheelbase 540 mm. Standee base center is 40 mm aft of case-top center.

Do not stand the suitcase upright. Do not insert the board into the cavity. Do not make an A-frame. Do not use mecanum wheels. Do not make the board taller than 1500 mm above the case lid. Hide the telescopic handle. Put 8 × 1 kg ballast blocks on the inner floor. Strap the board with three ratchet straps around case + board.

Parts: case_26, chassis, wheel_drive ×2, wheel_caster ×2, standee, strap ×3, ballast ×8, imu_block 20×20×4 on the back of the board at 700 mm height, ESP32 box 80×50×30 on the inner rear wall.

Optimize in this order: lower CG, keep straps off the face art, chassis not proud of the case by more than 20 mm, wheels clear of the shell.

Deliver assembly, exploded view, envelope size, estimated CG with masses case 6 kg + ballast 8 kg + board 1.2 kg + chassis 2 kg. Also a 24-inch variant: 660 × 430 × 270, track 360, wheelbase 480.

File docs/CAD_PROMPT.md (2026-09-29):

# 本地建模 Prompt

> 历史横放 prompt，已停用。当前为竖立行李箱、立牌贴箱前方，请复制 [当前 prompt](PROMPT_STAND_HANDLE.md)；下文只保留旧方案记录。

把下面整块贴进 Fusion 360 / SolidWorks / Blender / 任何 CAD Agent。
不要改结构定义。可以改圆角、壁厚、开孔、减重。
优先出 **26 寸**，再拷贝出 24 寸配置。

---

注意：以下是已停用的横放方案；当前装配必须采用 `docs/PROMPT_STAND_HANDLE.md`，不要执行下文旧姿态约束。

你是机械结构工程师。为项目「移动奶龙」建一个可装配的 CAD 模型。

## 产品

一只 26 寸硬壳行李箱躺在最大面上，当配重和载重底盘。
一块 1500 × 500 × 8 mm 的 KT 立牌绑在箱子顶面，画面是黄色卡通幼龙（奶龙）正面。
箱底下是一块平的驱动底盘板：后两轮差速驱动，前两轮万向从动。
整机像一辆慢慢走的载重小车，不像机器人赛小车。

## 坐标

- 原点在箱底面几何中心。
- +X 前进。+Z 向上。
- 箱子躺平：脚印 720 × 470 mm，壳厚 290 mm。
- 底盘板厚 8 mm，在箱底下面，外轮廓 50 mm。
- 轮半径 50 mm。左右轮距 400 mm。轴距 540 mm。
- 立牌在箱顶，板面法线 +X（正脸朝前）。板底中心比箱面中心偏 -X（40 mm）。

## 结构约束（不要破）

1. 箱子必须躺平。不准竖箱走。
2. 立牌在箱顶上，用三道紧缩器带绑住。不准把板插进箱腔。不准人字双板。
3. 拉杆不要露出箱外。
4. 配重贴箱底内表面，8 块 1 kg，均布。
5. 不要麦克纳姆轮。
6. 不要把立牌加到 1800 mm 以上（从箱顶算）。
7. 整机外观：箱子黑或深灰，板黄色简洁立牌。不要赛车形状件。

## 要输出的零件

1. `case_26` 行李箱壳外表皮，圆角 20 mm。可以空心，壁厚 3 mm。
2. `chassis` 矩形底盘板，四角开轮轴孔。
3. `wheel_drive` × 2，后轴。
4. `wheel_caster` × 2，前轴。
5. `standee` 1500×500×8 板。
6. `strap` × 3，环绕箱+板。
7. `ballast` × 8。
8. `imu_block` 20×20×4，贴在立牌背面中高 700 mm 处。

## 优化目标（按顺序）

1. 不倒：降低整机重心，加宽轮距优先于加高板。
2. 绑带不挡视线，从立牌两侧绕到箱底。
3. 底盘板不超出箱轮廓 20 mm 以外。
4. 预留 ESP32 盒 80×50×30，贴箱内后壁。
5. 轮胎不与箱壳干涉。

## 交付

- 装配体 + 爆炸图
- 整机外形尺寸
- 估算重心坐标（箱 6 kg + 配重 8 kg + 板 1.2 kg + 底盘 2 kg）
- 24 寸变体：脚印改 660 × 430 × 270，轮距 360，轴距 480，其它不变

开始建模。先放箱和板，再放轮，最后放绑带。

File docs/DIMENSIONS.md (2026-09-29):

# 24 / 26 寸待机尺寸

> 历史横放方案：当前模型为高 720、宽 470、深 290 mm 的竖立箱体，尺寸与轮位以 [当前 prompt](PROMPT_STAND_HANDLE.md) 为准；下文保留旧设计记录。

市面硬壳外径不统一。建模先用这两档。买到真箱之后用实测覆盖 `case.actual`。

坐标：箱子躺平，最大面贴地。X 前进，Y 左右，Z 向上。

## 24 寸

| | mm |
|---|---|
| 脚印 X（长） | 660 |
| 脚印 Y（宽） | 430 |
| 壳厚 Z | 270 |
| 轮后台面高（含 50mm 底盘） | 320 |

## 26 寸（优先）

| | mm |
|---|---|
| 脚印 X | 720 |
| 脚印 Y | 470 |
| 壳厚 Z | 290 |
| 轮后台面高 | 340 |

## 立牌

| | mm |
|---|---|
| 板高（从箱顶算） | 1500 |
| 板宽 | 500 |
| 板厚 | 8 |
| 绑带宽 | 40 |
| 绑带道数 | 3（距箱顶 80 / 400 / 800） |
| 板底超出箱后缘 | 0（端面落在箱面内，偏后 40mm） |

地面到龙头：24 寸 ≈ 1820 mm；26 寸 ≈ 1840 mm。等高探头用这个高度，不要再加高板。

## 轮距

| | 24 | 26 |
|---|---|---|
| 左右轮距 | 360 | 400 |
| 前后轴距 | 480 | 540 |
| 轮径 | 50 | 50 |

## 配重

箱内均布贴底 8 kg（建模用 8 个 1kg 块）。不放箱盖里。

## 倾覆检查（建模时算一下）

静止侧向：`g * (Y/2) > a_lat * h_cog`

待机：整机重心高 ≤ 450 mm。板轻、箱沉。
设计加速 ≤ 0.25 m/s²，设计速度 ≤ 0.30 m/s。

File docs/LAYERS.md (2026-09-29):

# 任务分层

> 历史横放方案：当前已改为正常竖立行李箱、立牌贴箱前方，见 [当前 prompt](PROMPT_STAND_HANDLE.md)。下文“绑箱顶”等旧分层不再作为装配要求。

从下往上做。下一层没过关，不开上一层。

```
L5  跟随 + 语音
L4  遥控限速 + IMU 防倒
L3  立牌 1.6 m 绑箱顶
L2  箱子部在底盘上（V1 不开箱）
L1  底盘能慢走、能载 20 kg
L0  选型：26 寸硬壳 + 1.6 m 立牌
```

V1 = L0 → L4，箱子可以用扎带死死扎在底盘上，**不考虑打开**。  
V2 = 底盘让开盖、轮孔避开钥匙和拉杆。

现在只推 L0 + L1。

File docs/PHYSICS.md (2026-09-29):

# 重心与防倾

> 历史横放计算：不适用于当前竖立箱体，不能据此判断当前装配稳定性；当前几何见 [当前 prompt](PROMPT_STAND_HANDLE.md)，稳定性需按新姿态与实测质量重算。

立牌 **1.6 m**（从箱顶算）。箱 26 寸躺平。

## 待机质量

| | kg | 质心高 mm（离地） |
|---|---|---|
| 底盘 | 3 | 50 |
| 箱 | 5 | 180 |
| 配重 | 8 | 80 |
| 立牌 1.6 m | 1.5 | 360+800=1160 |
| 合计 | 17.5 | **约 220 mm** |

板若达 2.5 kg，整机重心升到约 280 mm。板必须轻。

## 静止

半轮距按 200 mm算：
侧向允许加速 ≈ g × 200 / 220 ≈ 0.9 g。数字很宽。
真正会倒的是：原地甩尾、板枪转弯、侧风、有人撕板。

## 硬限制

- 速度 ≤ 0.30 m/s
- 加速 ≤ 0.25 m/s²
- 转弯半径 ≥ 1.5 m（不许原地转）
- 板背 IMU >8° / 200 ms → 断电机
- 侧推 2 N，倾 < 5°

## 测试顺序

1. 底盘空走
2. 底盘 + 箱 + 8 kg
3. 再绑 1.6 m 板
4. 慢转、急停、侧推

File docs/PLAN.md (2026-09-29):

# PLAN · 移动奶龙

> 历史横放方案：当前已改为正常竖立行李箱、立牌贴箱前方，见 [当前 prompt](PROMPT_STAND_HANDLE.md)。下文旧结构与阶段安排保留备查。

锁定日：2026-09-29

## 定义

行李箱 = 配重 + 载重小车。
奶龙立牌 = 绑在箱子**上面**。
箱子可以移动、可以遥控。

不是：胶贴贴片、人字撑、把板插进箱里、全校园 SLAM。

## 解决什么

1.7 m 立牌搬一次就烦，静止打卡会梗死。人推着走出戏。移动奶龙把「搬板」变成「板自己来」。

## 形态

```
侧视，行进方向 →

         奶龙头
          |
          |  KT 立牌 ~1500 mm（箱顶算起）
          |
     +----+----+
     | 8eba平箱 |
     | 配重     |
    ●          ●     前从动万向轮
    ●          ●     后驱动减速轮
```

- 24 寸或 26 寸硬壳。优先 26 寸（脚印更大）。
- 箱子躺在最大面上。拉杆收起或拆掉。
- 原装万向轮拆掉，换一块带电机的底盘板，用原轮螺丝孔或拐带筋在箱底。
- 立牌用紧缩器带 / 扎带 / 魔术贴跨过箱面绑死，绑点靠箱面中心偏后。

## 优先级

1. 人推装箱的板走一圈不倒
2. 遥控慢走、慢转、不摔板
3. IMU 倾角急停
4. 语音（靠近笑一声）
5. 跟随主人手机 BLE

## 技术主轴

防倾 > 跟随 > 语音。
不做视觉跟人、不做课表自主出巢、不做大模型控车。

## 能卖的东西

通用「立牌行李箱底盘」。奶龙只是演示皮肤。

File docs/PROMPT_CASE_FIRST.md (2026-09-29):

# PROMPT · 先只出箱子

> 历史箱壳建模记录：下文横放坐标只用于原始壳体，当前总装已改为竖立行李箱、立牌贴箱前方，见 [当前 prompt](PROMPT_STAND_HANDLE.md)。不要直接将此旧 prompt 用于新总装。

从下面分隔线复制到文末，整块贴给本地 Claude / Codex。本轮只交付 26 寸箱壳，先看外形再改。

---

注意：以下保留历史壳体源坐标；当前装配姿态已由 `docs/PROMPT_STAND_HANDLE.md` 替代，禁止据此恢复横放总装。

你在仓库 `mobile-nailong` 里做机械设计。这一轮 **只设计行李箱壳**。

不要设计轮子、轴、电机、底盘板、奶龙立牌、绑带、电路或 ESP32 盒。那些下一轮才做。本轮交付一只空心、可导出 STL / STEP 的 26 寸硬壳箱，外形要像真实行李箱，有圆角和清楚的两半分型，不是一块砖。不要改成 24 寸。

## 坐标与外形

箱子躺在最大面上；+X 是未来前进方向，+Z 向上。原点是箱底外表面几何中心。箱顶以后绑 1500×500×8 mm 立牌，箱底以后装驱动底盘；这两件只作为外形背景，本轮不要建模。

- 合装外形固定为 X×Y×Z = **720×470×290 mm**。
- 包围盒必须是 **X=[−360,360]、Y=[−235,235]、Z=[0,290] mm**。
- 空心壳；常规壁厚 3 mm，外圆角 R20、对应内圆角 R17；材质标注 ABS，预览深灰色。
- 造型可在基准外形以内微调最多 5 mm，必须仍保留上述包围盒极值；平台、凹槽、分型细节不得向外撑大包围盒。
- 只分底壳与箱盖：**底壳 Z=0…170，箱盖 Z=170…290，分型面 Z=170 mm**。以这些数值为准，不按“偏底”等口头描述改高度。

## 必须有的特征

1. **底壳先做。** 内底面平，基准内底 Z=3 mm；预留 8 个净空 **100×50×40 mm**（X×Y×Z）的配重位，只用浅槽或低定位框标记，不生成配重块。合理默认：中心 X=−210/−70/+70/+210、Y=−85/+85 mm，净空从 Z=3 起；定位框高 2 mm，框放在净空以外。
2. 箱底四角各有 **60×60 mm** 轮组装配平台，平台中心及轮孔 XY 坐标为 **(−270,−200)、(−270,+200)、(+270,−200)、(+270,+200) mm**，对应轴距 540、轮距 400 mm。孔沿 Z 贯穿。M6 默认按 **Ø6.6 mm 光孔**处理，明确这是可调整的装配间隙假设，不画螺纹。平台外表面保持 Z=0，需要补强时向壳内加料。
3. **再做箱盖。** 顶面有三道沿 Y 方向的浅槽，中心 X=**−80/0/+80 mm**，每道沿 X 宽 **40 mm**、深 **2 mm**；合理默认沿 Y 长 400 mm，两端圆滑收口。槽下内表面随外表面内移，**槽底仍保留至少 3 mm 壁厚**，不能直接把原 3 mm 壳切成 1 mm。
4. 后端 **−X 窄端**只做收起拉杆的凹槽，不生成拉杆。合理默认槽沿 Y 宽 160、沿 Z 高 50、中心 Z=120、深 4 mm；内侧补料保留至少 3 mm 壁厚。
5. 前端 **+X 外壁**有三个 **Ø18 mm** 通孔，孔轴沿 X，孔心距箱底 **Z=40 mm**。合理默认孔心 Y=−120/0/+120 mm。
6. 后端 **−X 内壁**有 **80×50 mm** 平台（沿 Y×沿 Z），给未来 ESP32 盒。合理默认中心 Y=0、Z=55 mm，与拉杆凹槽分开；只建平台，不建盒或电路。

未指定的定位框厚度、平台补强厚度和凹槽过渡圆角采用合理默认值，并集中参数化。不要自动增加轮子、把手本体、装饰附件或整机结构。

## 建模与交付

优先使用可回源的 **CadQuery**，源文件放在 `cad/case26/case26.py`。先生成底壳，再生成箱盖，最后按以上坐标合装。验证各壳是有效实体、空腔与孔连通、壁厚和合装包围盒正确。

在 `cad/case26/` 交付：

1. `case26.py`：参数化源文件，能单独生成底壳、箱盖和合装。
2. `case26_base.stl`、`case26_lid.stl`：两半独立 STL；`case26.stl`：合装 STL。
3. `case26_base.step`、`case26_lid.step`、`case26.step`：两半独立及合装 STEP。
4. 可直接查看外形的预览，展示底壳、箱盖与合装，能看清分型、前孔、顶槽和底部平台。
5. `NOTES.md`：**十行以内**，写外形、分型高度、四个轮孔坐标/孔径、三道顶槽 X 位置、关键默认值和复现命令；如导出受环境限制，明确列出未生成项，不伪造成功。

独立零件默认保留装配坐标。需要打印摆放时另存带 `_print` 后缀的文件，允许仅在打印导出中翻转箱盖并贴平打印基准；不得把主模型竖起来或悄悄改变原点。未指定打印机尺寸，不擅自分块，也不承诺适配桌面打印机。

先出箱子。外形不对先改包围盒和分型，别顺手把轮子和龙建上。不要写长说明书，短注释即可。完成后停下，等我看外形再改。

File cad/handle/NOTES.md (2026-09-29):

# 竖箱拉杆（单位mm）
箱高720、宽470、深290，箱底Z70/顶Z790；原箱文件不改。
拉杆最高Z1140，露出箱顶350；双管Ø12、壁厚1.2、管距180。
管轴X139/Y±90；管底Z710，嵌入箱顶以下80，前切面X145贴板背。
横杆180(Y)×20(X)×15(Z)，X125…145/Z1125…1140，与两管组成杆架。
两导座X123…145、Y中心±90宽26、Z700…790；Ø12.4开口导孔，径向间隙0.2。
底肩Z700…706；seat_cutters()给另加0.2装配间隙的座槽切削体。
奶龙板最低脚尖Z20，默认高1600/头顶Z1620；背面概念压条中心Z920/1080，替代原三绑带。
导出杆架、左右座及handle.step/stl；运行python cad/handle/handle.py。

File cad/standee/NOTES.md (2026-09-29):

# 竖箱 + 奶龙轮廓立牌（mm）
箱体高720×宽470×深290，Z70…790；原case26不改，仅总装副本开拉杆座槽。
奶龙8厚KT轮廓板，默认高1600/宽792.2，按照片比例；--height范围1600…1800。
板背X145贴箱身/双管，最低脚尖Z20；默认头顶Z1620，1800板头顶Z1820。
拉杆伸出箱顶350，顶Z1140，双管Ø12/管距180，固定板背中段。
背面概念横压条250×16×30，中心Z920/1080；无正面绑带，夹具和承载待定。
普通被动轮Ø50，中心X±105/Y±200；左右距400/前后距210，旧540属横放孔距。
奶龙图案为零厚度预览面与front_artwork.svg；STEP只含轮廓板，不含印刷图案。
运行handle.py、nailong_profile.py、standee.py、render_preview.py生成；整装standee_assembly.step/stl。
仿真见simulation/，材料/功能见docs/BOM.md及FUNCTIONS.md；当前未装电机，未实测承载。

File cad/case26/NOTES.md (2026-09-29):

# 26 寸箱壳首版（mm；ABS 深灰）
外形 720×470×290，X ±360 / Y ±235 / Z 0…290；外 R20、内 R17、基础壁厚 3。
分型 Z=170；底壳高 170、箱盖高 120；本轮仅两片箱壳，合装 STEP 保留独立实体。
四个 60×60 轮平台齐平 Z=0；孔 XY=(-270,-200),(-270,200),(270,-200),(270,200)，M6 默认 Ø6.6 光孔。
三条顶槽 X=-80/0/80，沿 Y 长 400、宽 40、深 2；内侧补料使槽底仍厚 3。
配重净空 100×50×40×8，中心 X=-210/-70/70/210、Y=±85，平底 Z=3，定位框高 2；不含配重块。
前 +X 端 Ø18×3，Y=-120/0/120、Z=40；后 -X 端拉杆凹槽 160×50×4、中心 Z=120。
后内壁平台 80(Y)×50(Z)，中心 Z=55、安装面 X=-354；无电盒、拉杆、锁扣或铰链。
复现：`python -m pip install -r cad/case26/requirements.txt` 后 `python cad/case26/case26.py`；预览运行同目录 `render_preview.py`。
`case26.stl` 仅合装看形；打印用底壳 STL 与 `case26_lid_print.stl`（盖翻转落地）；需适配 720×470 大幅面设备，尚未实打/承载验证；先评外形。

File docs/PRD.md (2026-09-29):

# PRD · 智能改装行李箱 / 流动奶龙

版本 0.1 · 2026-09-30 · 状态：需求评审稿，尚未实物验收。

## 1. 产品定义

把普通行李箱改造成平稳、可手机遥控、能自动跟随主人的智能行李箱。装上可拆奶龙立牌，就变成会跟人、会登场的“流动奶龙”；拆下外观后，仍应保留装物、开箱和手推能力。

用户明确的核心：爆改行李箱、控制平稳、手机遥控、自动跟随，以及奶龙带来的喜剧效果。“神出鬼没”落实为操作者控制下的惊喜登场动作。**自动跟随属于完整产品的必交付能力，遥控成功不等于产品完成。**

本文定义要解决什么、做到什么程度；[PDR](PDR.md)讨论结构与技术是否可行；[BOM](BOM.md)列材料和候选件。下列量化验收中，标为“建议”的数字是供评审的起点，不代表用户已确认或实测达成。

## 2. 用户与使用场景

| 场景 | 用户希望得到的体验 | 产品表现 |
|---|---|---|
| 搬运与布展 | 奶龙自己慢慢走过来，不用一直抱着板 | 手机控制前进、缓转、停靠；松手即发出停车请求 |
| 跟随主人 | 主人走、箱子跟；主人停、箱子停 | 明确绑定一个目标，维持跟距；不误跟其他人 |
| 惊喜登场 | 奶龙从布置好的场景边缘慢慢出现，停住形成笑点 | 按住执行一次短动作，随时能停；可选手动音效 |
| 日常用箱 | 拆掉奶龙后仍是可用的行李箱 | 能开箱取物、手推搬运；裸箱跟随单独验证 |

首轮试验在有人看护的平整室内空地进行。户外、坡道、台阶和拥挤场地不包含在首轮验收中，后续扩展需另列指标。

## 3. 两种形态与功能范围

| 形态 | 外形 | 运行需求 |
|---|---|---|
| 奶龙展示形态 | 竖立箱体在板后；切型板高1.6–1.8 m；脚接近轮底 | 优先平稳、低速和可控停靠，不能用突然加速制造喜剧效果 |
| 裸箱实用形态 | 奶龙与外接撑件可拆；保留箱盖与拉杆使用空间 | 遥控、手推、自动跟随；需单独评审日常步行速度与装载能力 |

当前外形基线：箱身高720×宽470×深290 mm；默认奶龙高1600、宽约792、厚8 mm，最低脚尖离地20 mm，总高1620 mm。1800板等比宽约891、总高1820 mm。20 mm间隙属于审形参数，实物可以根据地面和轮子包络调整。

| ID | 需求 | 优先级 / 交付条件 |
|---|---|---|
| R01 | 起步、转弯、停靠平稳；负载变化后仍可控 | 核心；所有运动模式共享限速、限加速度和停止逻辑 |
| R02 | 手机遥控：连接、使能、前进/转弯、停止、状态反馈 | 核心；工程首轮不开放倒车，补后向探测与验证后再开放 |
| R03 | 自动跟随一个明确绑定的主人/随身目标 | 核心；须测距与辨别相对方向，目标丢失必须停车 |
| R04 | 遥控优先接管自动模式，急停优先于全部动作 | 核心；切换运动模式先停再使能，复位不能自行启动 |
| R05 | 奶龙轮廓可辨识、可拆装、低位固定可靠 | 核心；正常竖箱，板贴箱外侧，不恢复横箱或箱顶叠板 |
| R06 | 奶龙“登场”动作 | 体验项；一次短动作，操作者保持控制；不得覆盖障碍/失联停车 |
| R07 | 行李箱基础用途 | 核心；开箱、储物、提拉和断电手推，避免改成永久封死的配重盒 |
| R08 | 可读的运行状态与故障原因 | 核心；至少显示连接、模式、目标状态、电量、停车原因 |
| R09 | 手动音效、后续更多角色外观 | 可后续增强；不影响核心跟随验收 |

当前不承诺：任意手机无需额外硬件即可提供精确跟随方位、全校园自主导航、自动绕过视线外障碍、载人骑行或无人值守运行。先将“跟准一个主人、稳稳停下”做实。

## 4. 手机端与交互

建议首屏仅包含：设备连接/电量、遥控/跟随/登场模式、启动使能、持续可见的停止按钮、当前故障原因。手机是操作界面，不要求用户配置机器人技术参数。

1. **连接**：选择自己的箱子，显示已连接但保持待机；单一控制端持有控制权。
2. **遥控**：按住摇杆输出速度请求，松手归零；失联也归零。手机停止不替代箱体实体急停。
3. **跟随**：绑定目标 → 确认目标有效/方向合理 → 人工启动 → 跟随；靠太近、目标走太远或丢失则停，不盲追。
4. **接管**：停止或切换遥控优先终止跟随/登场；重新取得目标后由用户明确继续，不能突然补跑。
5. **登场**：建议首次仅执行前进≤1 m、持续≤5 s的一次动作，按住才执行，松开/到点/遇障即停止；距离与时间以先到者为准，不循环、不无人定时触发。
6. **收纳**：断开动力使能，拆奶龙，确认箱盖与手推可用。换装后必须切换到对应速度配置。

## 5. 量化验收建议

下表为待评审目标；几何尺寸来自当前粗模，其余除已注明的计算值外均未验证。试验需记录实际质量、载荷、地面、板高、软件版本和原始日志，不能只交一段成功视频。

| ID | 项目 | 建议目标与测法 |
|---|---|---|
| A01 | 奶龙模式运动边界 | 首轮≤0.30 m/s、加速度≤0.25 m/s²、转弯半径≥1.5 m；记录编码器与IMU曲线，不原地甩尾 |
| A02 | 平稳性 | 空载/建议5 kg载物两档，各10次起停+10次左右缓转；不倒、不擦板脚、不松夹具；建议直行稳态速度误差≤10%，暂用视频测板顶摆幅并在结构评审确定阈值 |
| A03 | 遥控与失联停止 | 有效指令过期200 ms内进入受控停车；0.30 m/s、平地条件建议最坏停距≤0.40 m；20次均记录通过。断电滑行和急停另测，不能套用此停距 |
| A04 | 低速跟随 | 建议目标跟距1.8 m，稳态范围1.5–2.1 m；30 m路线含两次缓转、三次起停，10轮至少9轮完成，稳态90%以上时间处于范围内 |
| A05 | 不误跟与目标丢失 | 插入旁人、遮挡、过期数据与断连各20次；不切换到陌生目标，进入停车且不自行重启；200 ms是目标信息有效期的初始建议，跟随传感器必须能支撑 |
| A06 | 障碍与接管 | 障碍检测覆盖整机扫掠宽度；20次接管/障碍停车无碰撞。触发距离由最坏实测停距加定位/检测余量确定，不能只用名义测距距离 |
| A07 | 奶龙拆装 | 建议1人≤5 min，重复10次后无松动；不用拆电池和重新接动力线；夹具不压坏KT板、不遮传感器 |
| A08 | 实用行李箱 | 建议有效储物空间≥改装前60%；5 kg载物下开合20次、断电手推10 m可用；测试值不足时必须调整结构或明确降级 |
| A09 | 续航 | 建议首轮样机完成30 min混合遥控/跟随/等待；报告各模式时长、里程和电量，不拿待机时长冒充移动续航 |
| A10 | 裸箱日常跟随 | 提出0.8 m/s作为待评审速度目标；必须重新选型并验证制动、稳定性与跟距。当前0.3 m/s粗模/仿真不能据此宣称已实现日常步行随行 |

预算上限、交付日期、手机系统、实际箱型号、载物与续航指标尚未由用户给定。表中的5 kg、30 min、0.8 m/s及允许随身标签都是评审假设；先据此暴露设计问题，评审后再冻结采购规格。

## 6. 实现阶段与产品完成标准

| 阶段 | 交付 | 通过条件 |
|---|---|---|
| M0 外形与方案审查 | CAD、PRD/PDR、BOM、初步仿真 | 另一Agent能复现并提出具体问题；选定实箱和固定路线 |
| M1 稳定遥控工程样机 | 驱动、手机界面、速度闭环、停车与故障状态 | A01–A03/A06相关试验通过；仅表示遥控样机完成 |
| M2 低速跟随 + 奶龙首个闭环 | 目标定位、跟随控制、换装与受控登场 | A04–A07通过；跟随是必做，不以遥控表演代替 |
| M3 实用智能行李箱 | 裸箱装载、开合、手推、续航、日常跟随 | A08–A10经评审冻结后通过，才能宣称“真正好用的智能行李箱” |

当前只交付M0所需资料与计算，M1–M3未实现。需求变化先更新本文，再同步PDR、功能方案、BOM和验收任务；不得把“计划支持”写成“已经具备”。

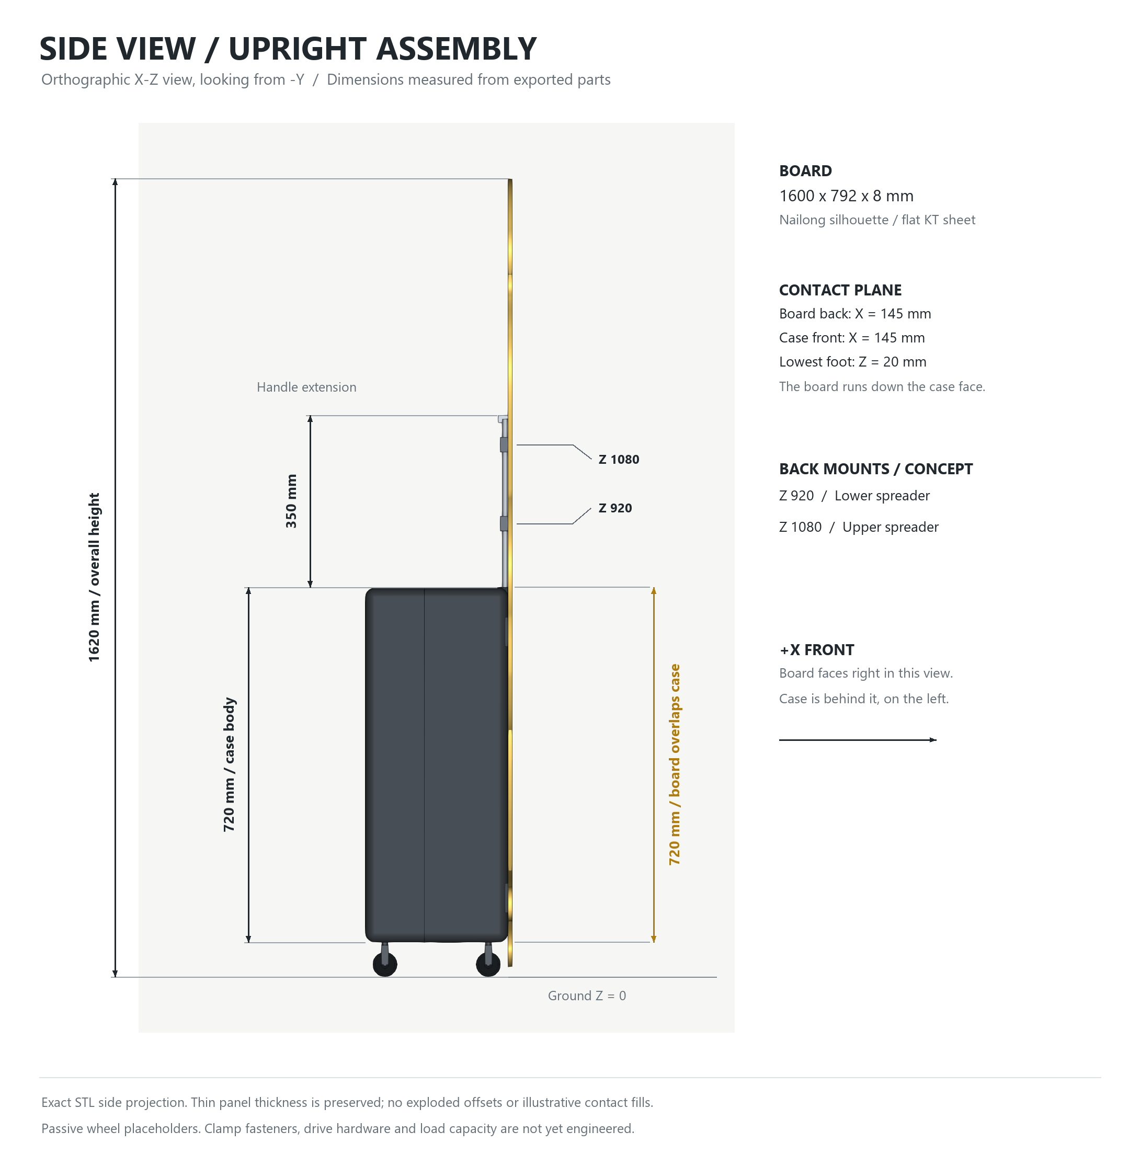
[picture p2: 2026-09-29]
cad/standee/upright_side.png

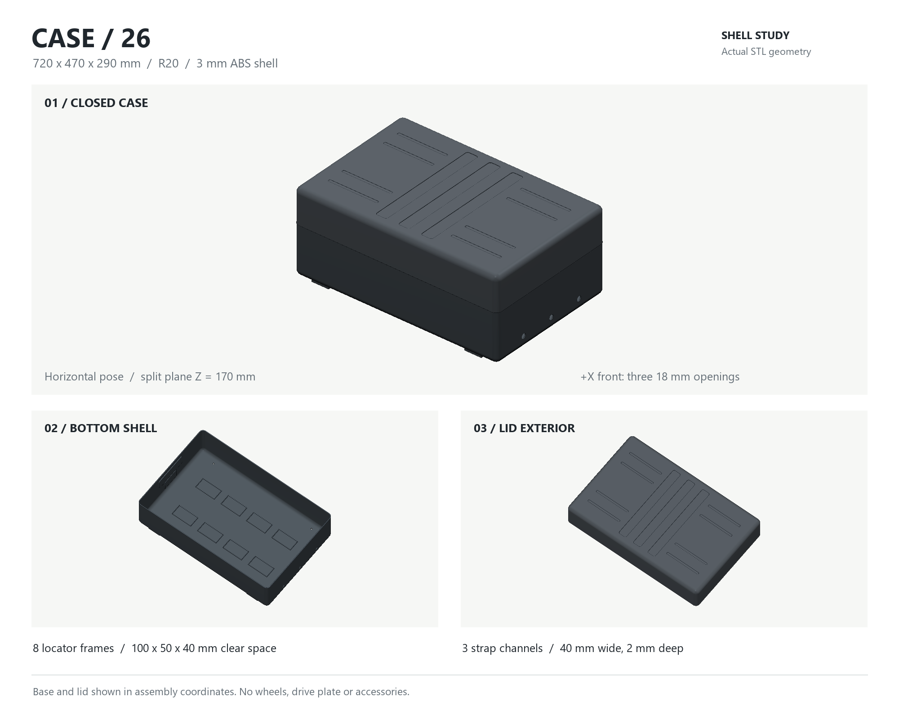
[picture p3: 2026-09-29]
cad/case26/case26_preview.png

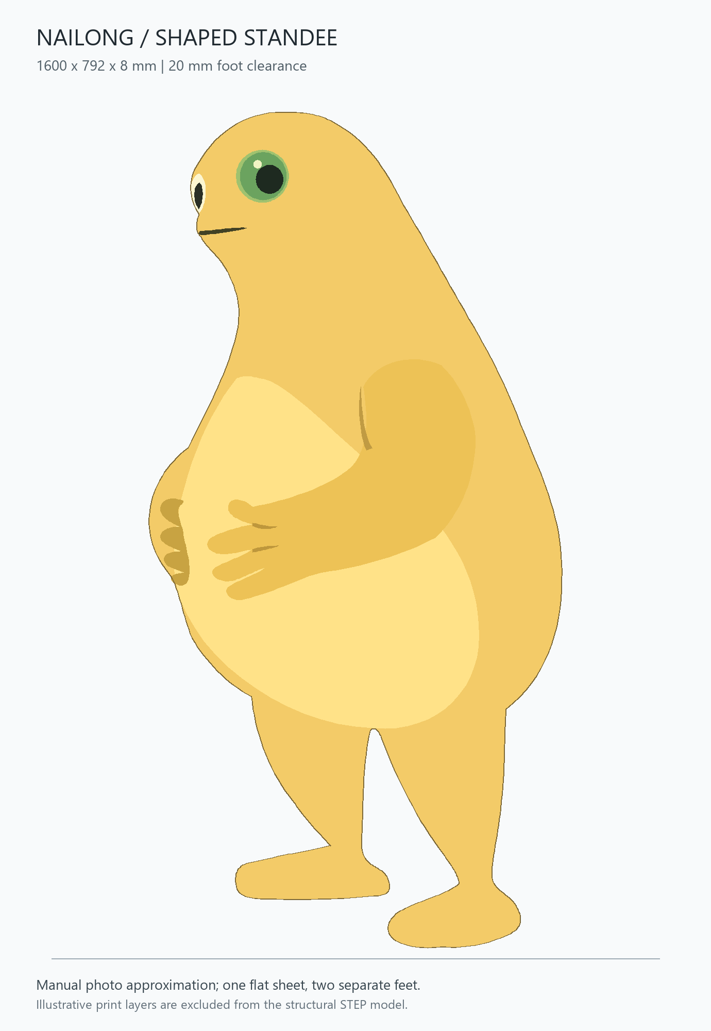
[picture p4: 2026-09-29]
cad/standee/profile_preview.png

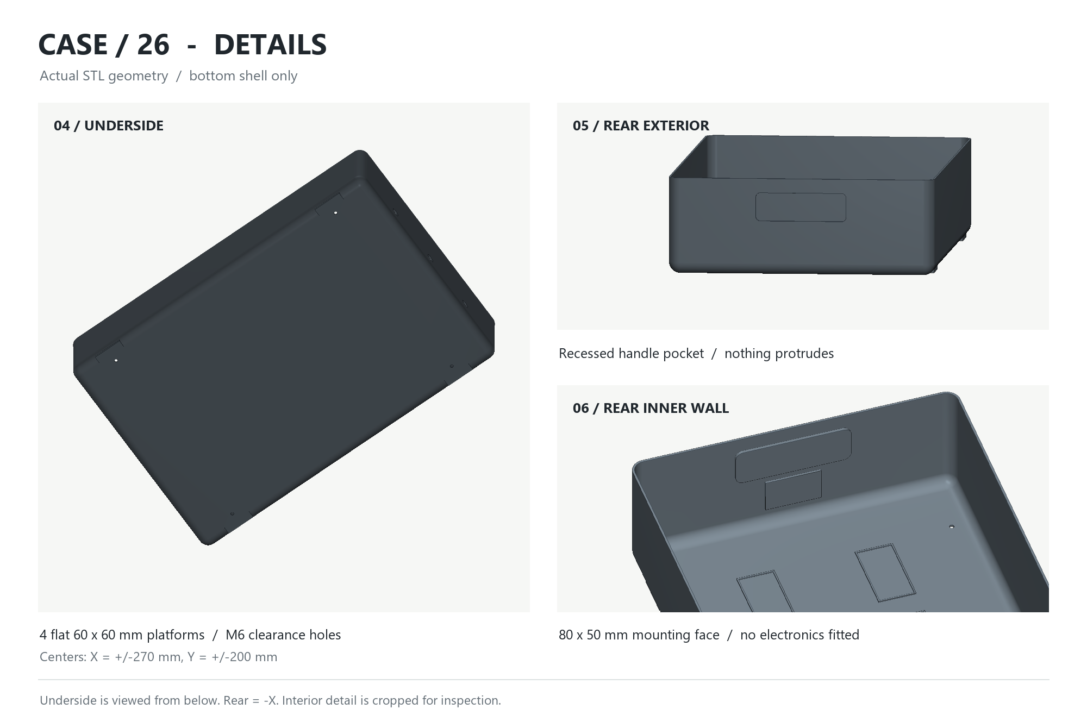
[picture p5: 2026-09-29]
cad/case26/case26_details.png

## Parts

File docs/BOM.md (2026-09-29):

# 材料与硬件清单 · 竖箱奶龙

先用 A 组核对外形和固定，再按仿真与实测选 B 组。当前仓库有外观 CAD 和普通箱轮，没有驱动底盘、电机装配或控制固件；“CAD 已有”不代表实物已备齐。价格、库存、实际承载均待询价，不沿用历史横箱预算。

产品需求见[PRD](PRD.md)、待审选型见[PDR](PDR.md)。B组只对应M1低速台架；自动跟随是M2必交付，C组定位件须在方案验证后选，不能漏算。裸箱0.8 m/s是待评审目标，现有200 rpm电机候选不满足Ø50轮的约306 rpm轮速需求。

## A · 外形与固定验证，先准备

| 物料 | 数量 | 建议规格或需求 | 作用 | 目前状态 | 来源或待测 |
|---|---:|---|---|---|---|
| 正常竖立硬壳箱 | 1 | 箱身高 720 × 宽 470 × 深 290 mm；现有箱优先 | 载体与低位容纳空间 | CAD 已有；实物待确认 | 实测壳体、轮座、内骨架和空箱质量 |
| 奶龙切型立牌 | 1 | 高 1600–1800 mm、厚 8 mm；按照片轮廓等比，1600 高时宽约 790 mm | 外观主体，脚底距地约 20 mm | 切型 CAD；实物待确认 | 用户照片只定轮廓；质量与弯曲刚度须实测 |
| 双管拉杆 | 1 套 | 管径 12、管距 180、露出箱顶 350 mm；基座嵌入并连到承力结构 | 背面定位与上部连接 | CAD 已有；承载未验证 | 普通拉杆锁止间隙、刚度与根部承载待测 |
| 轻量背撑 | 1 套 | 候选为两根薄壁铝条/管；长度和截面按实物弯曲测试确定 | 分散 KT 板载荷，抑制上半身晃动 | 方案待定，未出制造件 | 不让小螺钉、胶点直接承担全部板重 |
| 分压横条与夹持件 | 2 组 | 大面积压片、软垫、拉杆管夹；模型横条中心 Z=920 / 1080 mm | 板背与双管两点连接 | 粗模占位；孔位与夹紧力未定 | 先做板材压痕、拔脱、振动测试；不跨脸绑长带 |
| 下部承托/限位件 | 1 组 | 接箱体承力部位，支承板背或脚部，避开轮子转动包络 | 承担板重、限制前后摆动 | 待实物选位 | 20 mm 离地只适合先做平整地面验证 |
| 原箱万向轮 | 4 | 粗模 Ø50；中心 X=±105、Y=±200 mm | 外形与手推验证 | CAD 已有，普通从动轮 | 轮距 400、轴距 210；载荷和拖曳阻力待测 |
| 可拆低位配重及固定盒 | 1 套 | 仿真扫描不同质量；默认算例 6 kg，不是采购定值 | 降低重心 | 待仿真、称重后决定 | 固定在箱内最低承力处，不能自由滑动 |
| 螺栓、锁紧螺母、垫片、护边软垫 | 1 批 | 随承力件孔位选型 | 连接、防松、保护 KT 板 | 待选 | 薄 ABS 壳要配背板，不直接承受集中拉拔 |

## B · 动力台架候选，先验证再定型

| 物料 | 数量 | 建议规格或需求 | 作用 | 目前状态 | 来源或待测 |
|---|---:|---|---|---|---|
| 带编码器有刷减速电机 | 2 | 12 V 级；Ø50 平地算例单侧约 0.30 N·m，转弯外轮约 130 rpm；含 5° 坡选型门槛见下文 | 后两轮差速 | 未建模、未采购 | [Pololu 37D 50:1 候选](https://www.pololu.com/product/4753)，仅平地台架待验 |
| 固定驱动轮、轴承轮座与连接轴/轮毂 | 2 套 | 先保持 Ø50 比较；轮座承担径向载荷，按电机轴与承载选配 | 替换后两普通脚轮 | 待机械布局 | 不直接假定减速器轴能承受整机冲击载荷 |
| 电机支架与箱内加强件 | 1 套 | 扭矩传给箱内骨架；不能只拧在薄壳上 | 闭合驱动力路径 | 待结构设计 | 540 mm 历史轴距不用于当前竖箱 |
| H 桥驱动 | 2 路 | 3.3 V 逻辑、可制动、测流/限流；按电机最大供电电压下堵转电流选 | 双电机功率驱动 | 候选、未接线 | [Pololu G2 18v17](https://www.pololu.com/product/2991) 每板 1 路，候选数量 2 |
| ESP32 开发板 | 1 | ESP32-DevKitC V4 / WROOM-32E | BLE 遥控、双轮速度闭环、状态机 | 待选、无固件 | [官方板卡资料](https://docs.espressif.com/projects/esp-dev-kits/en/latest/esp32/esp32-devkitc/user_guide.html) |
| 逻辑电源与电平转换 | 1 套 | 合适输入范围的 5 V DC/DC；编码器 5 V 信号转 3.3 V | MCU/传感器供电，保护 GPIO | 待电路设计 | 上述 Pololu 编码器供电 3.5–20 V，输出幅值随供电，不能直接接 ESP32 |
| 成品电池与配套充电器 | 1 套 | 带 BMS、有适用认证的成品包；全电压范围匹配电机/驱动；容量按实测功率和目标时长定 | 供电 | 待选 | 核对持续/峰值放电能力与充电器；不采用裸电芯自组 |
| 急停、直流开断器件、保险丝、线束、连接器 | 1 套 | 急停切断电机电源；额定直流电压、电流及线径按限流/堵转实测定 | 硬件停止与配电 | 待选 | 急停按钮可控制合适接触器；MCU 保持供电记录故障 |
| 六轴 IMU 模块 | 1 | BMI270 或同类；接 3.3 V I²C/SPI | 箱体倾角/角速度检测 | 待选 | [Bosch BMI270](https://www.bosch-sensortec.com/en/products/motion-sensors/imus/bmi270)；刚性安装在箱体，板摆动另测 |
| 前方距离模块 | 3 | 中/左/右；可试 VL53L1X ToF 成品模块 | 近障停车 | 待选与视场试验 | [ST VL53L1X](https://www.st.com/en/imaging-and-photonics-solutions/vl53l1x.html)；不得被奶龙板遮挡，覆盖与阳光条件实测 |
| 触碰停机条 | 1 组 | 低位常闭触边/触碰开关 | 补充近地障碍检测 | 待选 | 外形需留出触发空间；不替代视场与制动测试 |

15.5 kg、滚阻系数 0.03、加速度 0.25 m/s²、效率 0.7、2 倍选型余量下：Ø50 的 5° 坡工况约需 **0.78 N·m/侧**；改 Ø80 则约 **1.24 N·m/侧**、转弯外轮约 **81 rpm**，同时必须重做离地高度和轮位校核。目标是该转速下的持续输出能力，不能用堵转扭矩代替。[仿真假设与复现](../simulation/README.md) · [本轮计算结果](../simulation/results.json)

Pololu #4753 的官方值为 12 V、空载 200 rpm、堵转电流 5.5 A；厂商还要求控制持续负载与工作电流。它可作为平地试验的参考，不据此承诺 5° 坡长期运行。G2 18v17 支持 3.3 V 逻辑、标称持续 17 A，但默认限流约 40 A，**必须按所选电机重设并实测限流与温升**；两电机原始堵转电流合计约 11 A，不能想当然配 10 A 电源。[电机使用限制](https://www.pololu.com/product/4753) · [驱动规格与限流方法](https://www.pololu.com/product/2991)

## C · 自动跟随必需能力，路线确定后选型

| 物料/路线 | 数量起点 | 需要满足的条件 | 当前状态 |
|---|---:|---|---|
| 支持方位测量的UWB完整评估方案 + 随身标签 | 车端1套、标签1个，按套件实际拓扑核对 | 输出目标ID、距离、方位、时间戳与质量；不能只买一对测距板 | 候选，未采购；[Qorvo测距/测角评估套件](https://www.qorvo.com/products/ek/QM33120WDK1)仅作路线依据 |
| 或：相机 + 本地计算单元 + AprilTag标记 | 相机/计算单元各1、标记1套 | 相机标定、已知标记尺寸、无遮挡视场与足够更新率 | 替代路线，未定硬件；[官方位姿估计说明](https://github.com/AprilRobotics/apriltag#pose-estimation) |
| 定位模块电源、支架与通信线 | 随路线1套 | 不能被奶龙/金属件遮挡；追加实际质量、峰值功耗和线束 | 待试验后回填CAD/BOM |
| 手机操作界面与车端跟随软件 | 1套开发工作 | 配对、使能、接管、目标失效停车与日志；不能视为现成硬件附送能力 | 尚未实现，工时与兼容手机范围待评审 |

UWB与视觉先择一验证，不默认两套都采购；接受随身标签与预算须在PDR冻结。声音后续再加：DFPlayer Mini + 配套喇叭 + TF卡各1，官方支持UART控制及板载3 W单声道功放。[DFRobot DFR0299](https://www.dfrobot.com/product-1121.html)

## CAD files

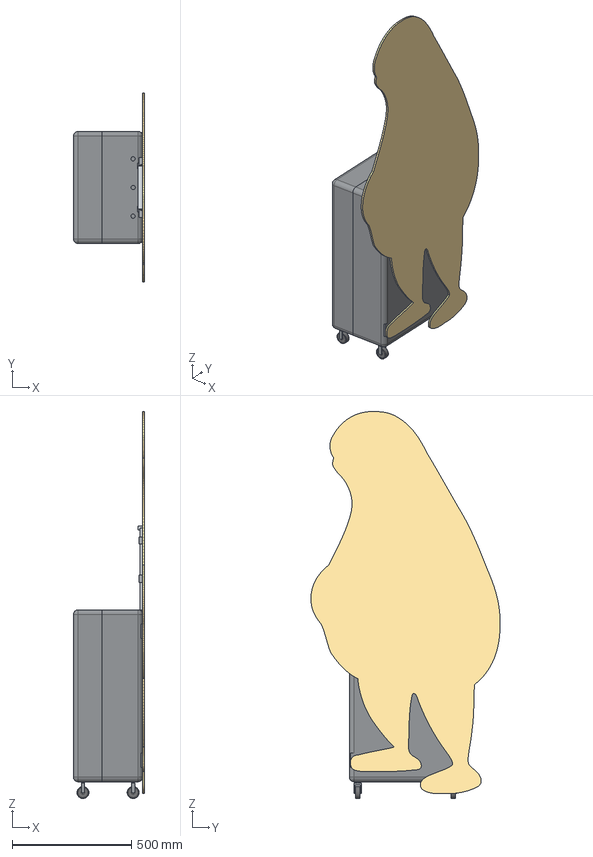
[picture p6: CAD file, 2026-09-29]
cad/standee/standee_assembly.step
298.0 x 792.2 x 1620.0 mm
case_base
case_lid
wheel_rear_left
fork_rear_left
wheel_rear_right
fork_rear_right
wheel_front_left
fork_front_left
wheel_front_right
fork_front_right
handle_frame
socket_left
socket_right
standee
mount_lower
mount_upper

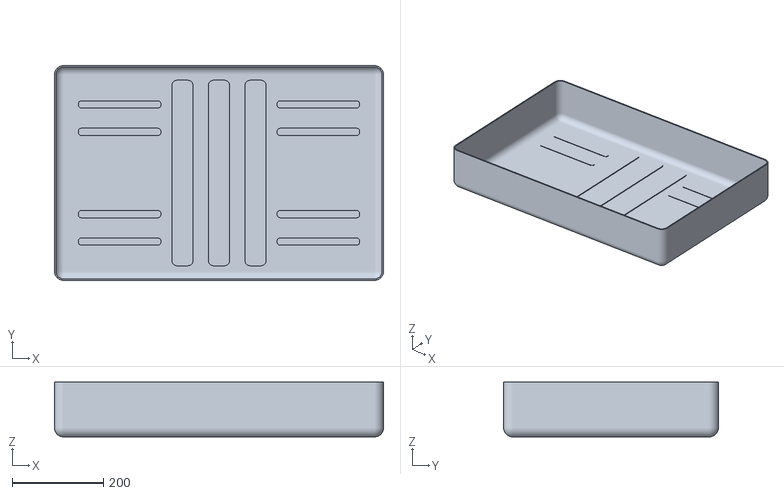
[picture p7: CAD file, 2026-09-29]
cad/case26/case26_lid_print.stl
720.0 x 470.0 x 120.0

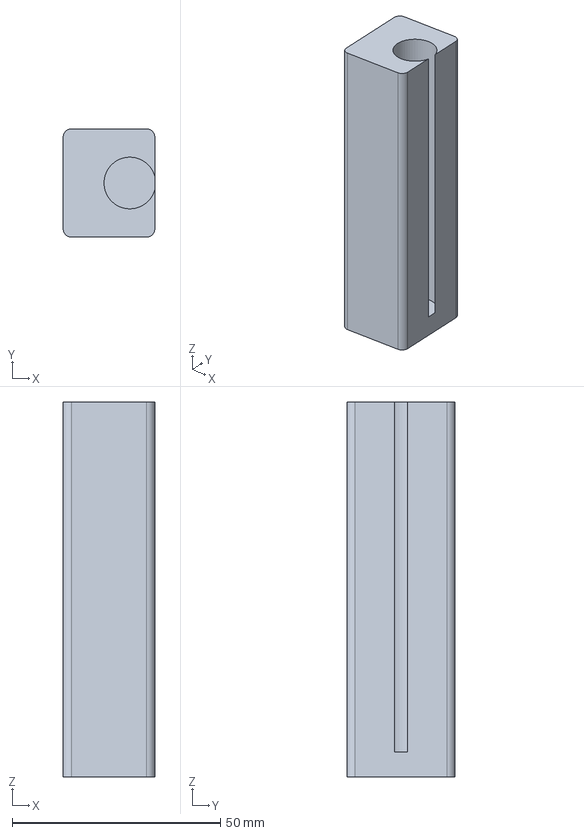
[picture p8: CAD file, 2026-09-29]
cad/handle/socket_left.step
22.0 x 26.0 x 90.0 mm

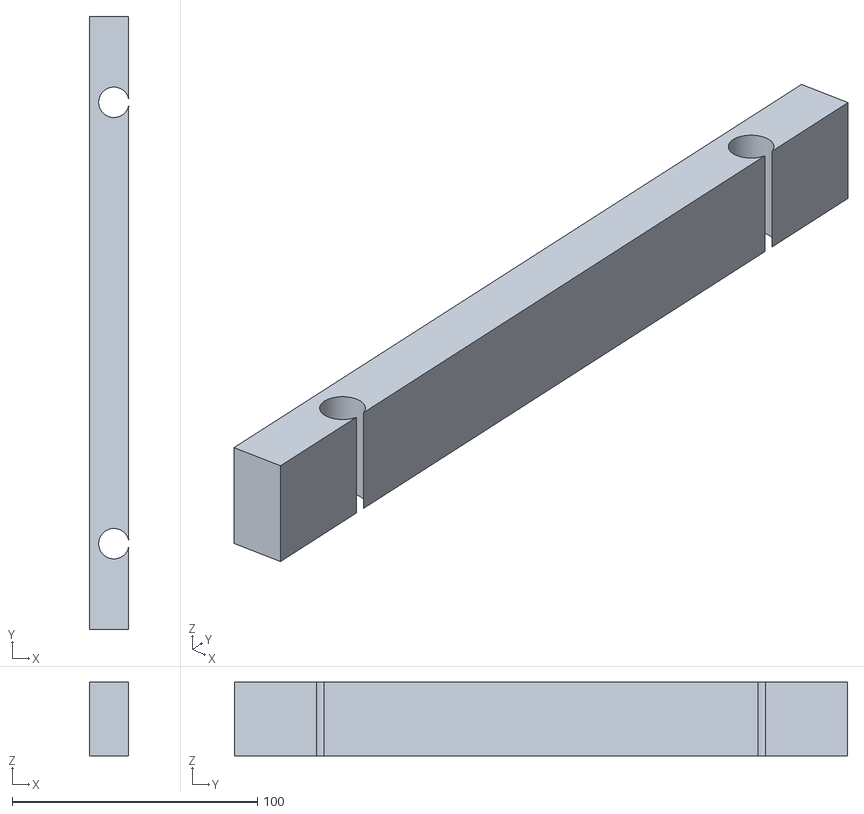
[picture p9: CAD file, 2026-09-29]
cad/standee/parts/mount_upper.stl
16.0 x 250.0 x 30.0

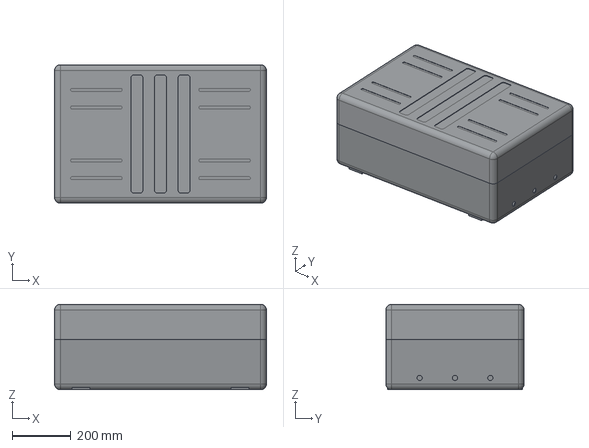
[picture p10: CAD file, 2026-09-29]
cad/case26/case26.step
720.0 x 470.0 x 290.0 mm
case26_base
case26_lid

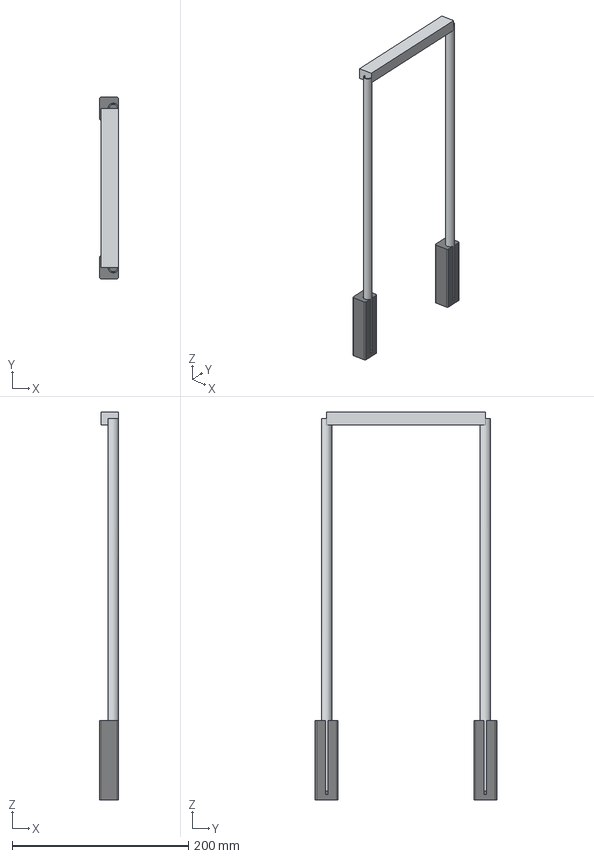
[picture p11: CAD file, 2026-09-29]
cad/handle/handle.step
22.0 x 206.0 x 440.0 mm
handle_frame
socket_left
socket_right

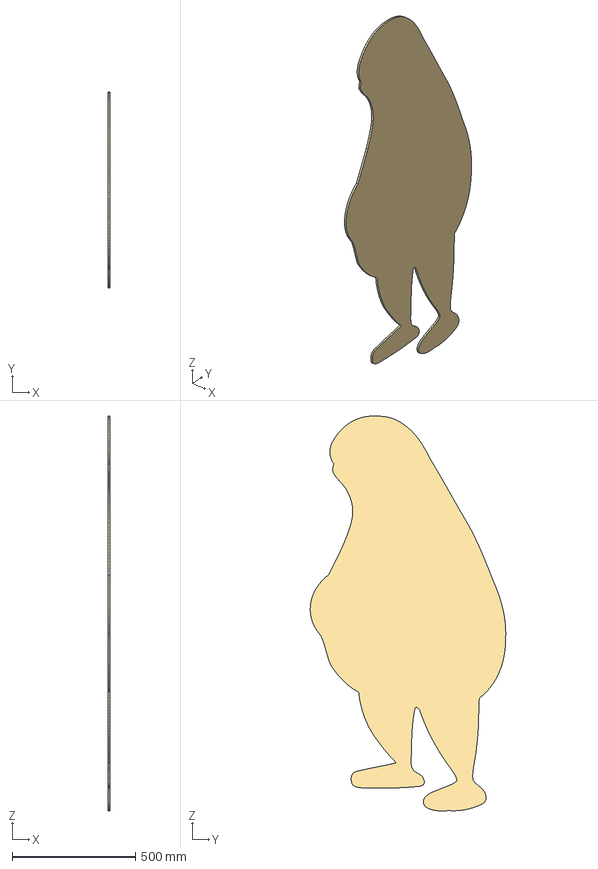
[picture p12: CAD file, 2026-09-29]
cad/standee/standee.step
8.00 x 792.2 x 1600.0 mm

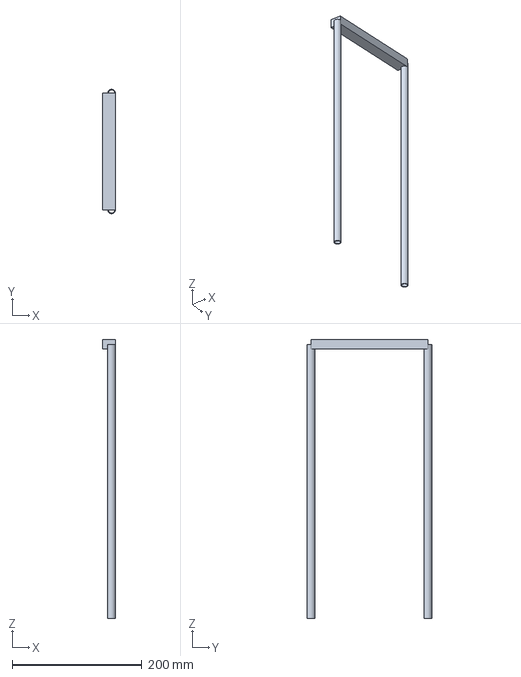
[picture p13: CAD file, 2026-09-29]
cad/handle/handle_frame.step
20.0 x 192.0 x 430.0 mm

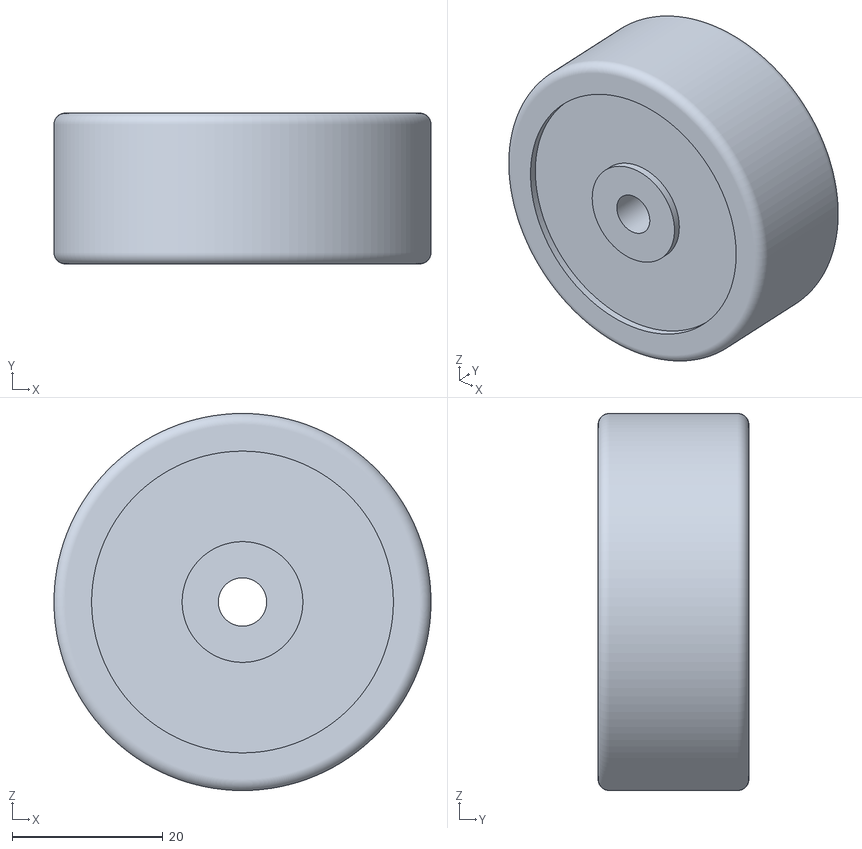
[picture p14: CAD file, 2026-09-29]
cad/standee/parts/wheel_front_left.stl
50.0 x 20.0 x 50.0

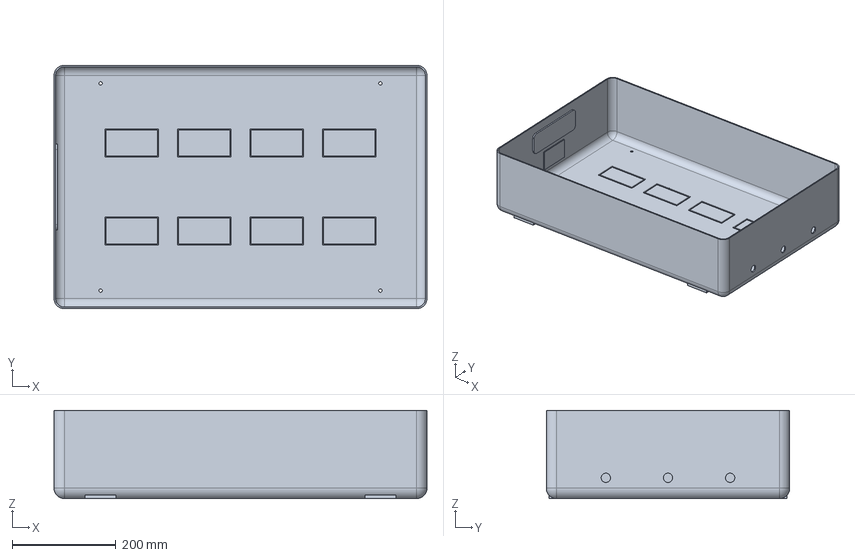
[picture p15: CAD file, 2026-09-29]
cad/case26/case26_base.step
720.0 x 470.0 x 170.0 mm

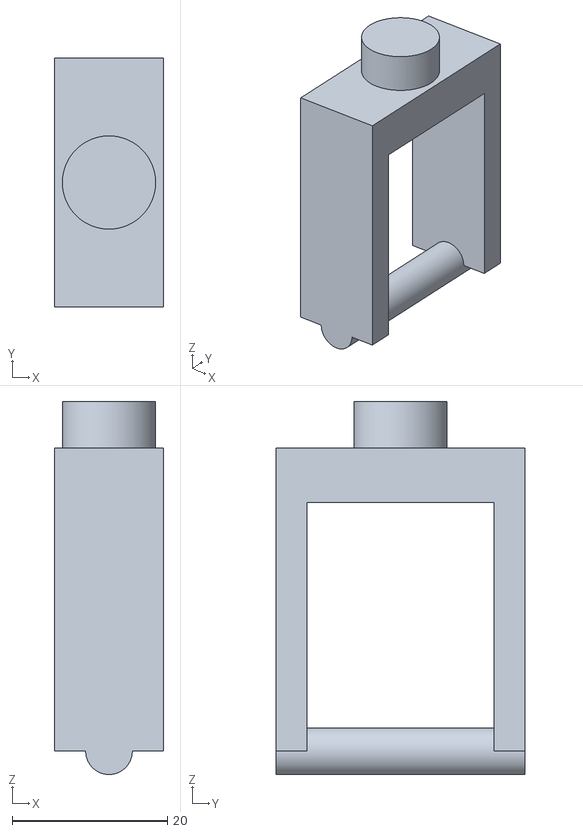
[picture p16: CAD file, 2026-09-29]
cad/standee/parts/fork_rear_right.stl
14.0 x 32.0 x 48.0

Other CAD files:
cad/standee/parts/socket_left.stl
cad/case26/case26_lid.step
cad/handle/socket_right.step
cad/standee/parts/case_base.stl
cad/standee/parts/socket_right.stl
cad/standee/parts/handle_frame.stl
cad/standee/parts/case_lid.stl
cad/case26/case26.stl
cad/case26/case26_base.stl
cad/case26/case26_lid.stl
cad/handle/handle.stl
cad/handle/handle_frame.stl
cad/handle/socket_left.stl
cad/handle/socket_right.stl
cad/standee/parts/fork_front_left.stl
cad/standee/parts/fork_front_right.stl
cad/standee/parts/fork_rear_left.stl
cad/standee/parts/mount_lower.stl
cad/standee/parts/standee.stl
cad/standee/parts/wheel_front_right.stl
cad/standee/parts/wheel_rear_left.stl
cad/standee/parts/wheel_rear_right.stl
cad/standee/standee.stl
cad/standee/standee_assembly.stl

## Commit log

2026-09-29 docs: lock 24/26 suitcase-as-ballast plan and CAD prompt
2026-09-29 docs: case-first prompt for local Claude / Codex
2026-09-29 docs: layered tasks, 1.6m standee, V1 chassis buy path
2026-09-29 docs: point README at layers; standee 1600 mm
2026-09-29 feat(cad): add case-only 26-inch suitcase shell and exports
    [case26.step, case26.stl, case26_base.step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]
2026-09-29 docs: chassis buy-vs-DIY ladder and schedule gate
2026-09-29 docs: chassis-next prompt after case exists
2026-09-29 docs: prompt add standee + trolley handle as mount point
2026-09-29 feat(cad): model upright Nailong standee and add motion feasibility study
    [case_base.stl, case_lid.stl, fork_front_left.stl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]
